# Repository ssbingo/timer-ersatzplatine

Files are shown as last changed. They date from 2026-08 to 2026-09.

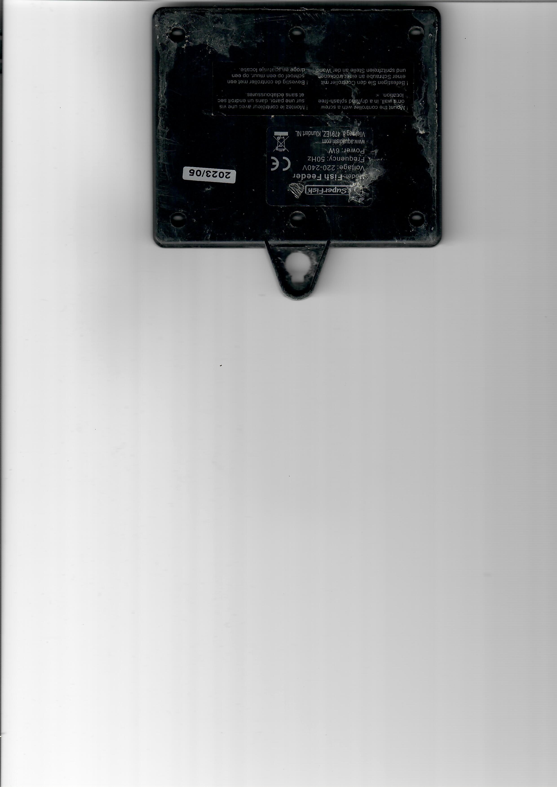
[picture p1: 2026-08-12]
box/aussen.jpg

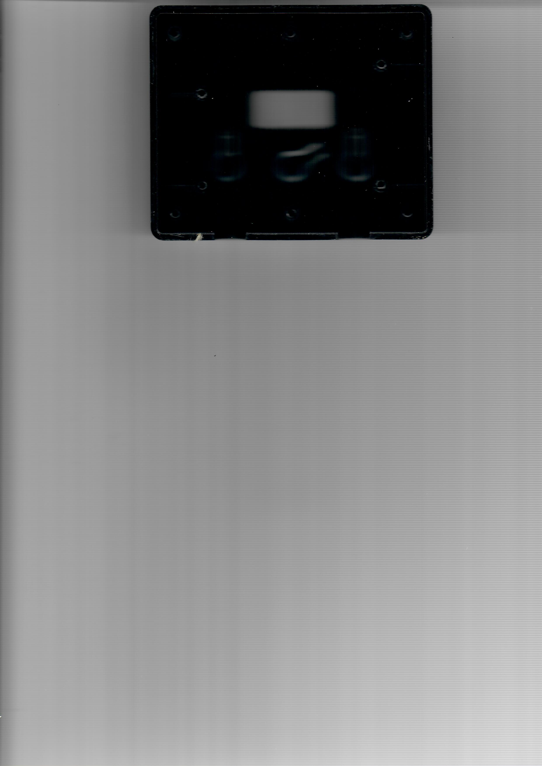
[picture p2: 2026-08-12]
box/Gehauesevorderteil.jpg

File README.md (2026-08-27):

# Feeder-Relais Logo Feeder-Relais

<p align="center">
  <a href="https://www.buymeacoffee.com/ssbingo">Buy me a coffee</a>
</p>

> **Herkunft:** Dieses Projekt ist der Umbau eines **SuperFish / Koi-Pro Fish Feeder** (Futterautomat von Aquadistri — [Produktreihe](https://aquadistri.com/de/brands/koi-pro/einrichtung-zubehoer/zubehoer/) · [Original-Handbuch (PDF)](docs/Koi-Pro-FishFeeder-Original-Manual.pdf)) — die defekte originale Zeitschaltplatine wird ersetzt. **Gehäuse-Rückteil und Platine orientieren sich an den Maßen der Originalsteuerung**, damit beides exakt in das vorhandene Gehäuse passt.

**230-V-Timer-Steuerung zum Selbstbau — ESP32-C3 · OLED · PhotoMOS · externer Shelly 1PM Mini Gen4**

Das Feeder-Relais ist eine selbstgebaute Steuerplatine, die eine 230-Volt-Last
auf Knopfdruck für eine **einstellbare Zeit** einschaltet und danach von allein
wieder abschaltet. Der Name stammt aus dem ursprünglichen Einsatz: Sie ersetzt
die defekte Zeitschaltplatine eines **Futterautomaten** (englisch *feeder*).
Weil sie im Kern nur „einen Schalter für eine gewisse Zeit drückt“, eignet sie
sich für jede Last, die zeitgesteuert geschaltet werden soll — Pumpe,
Futtermotor, Lüfter, Licht.

Drei Taster lösen drei getrennt einstellbare Zeiten aus (Standard 5/10/15 s),
ein OLED zeigt WLAN, Uhrzeit und den Countdown, und eine für Handys optimierte
Weboberfläche erlaubt Bedienung und Konfiguration im Heimnetz — **ohne App und
ohne Cloud**. Das eigentliche Schalten und die Leistungsmessung übernimmt ein
**externer Shelly 1PM Mini Gen4**; die Platine steuert dessen SW-Eingang über ein
**PhotoMOS-Relais galvanisch getrennt** an. Dadurch ist die Kernfunktion
**WLAN-unabhängig**.

> ### ⚠️ 230 Volt — Lebensgefahr
> Netzspannung kann tödlich sein. Aufbau, Prüfung und Inbetriebnahme der
> 230-V-Seite gehören in die Hände einer **Elektrofachkraft** oder unterwiesenen
> Person. Alle Tests, die ohne Fachkraft möglich sind, laufen **ausschließlich
> über USB und ohne jede Netzspannung**. Bitte zuerst Kapitel 2 des Handbuchs
> lesen.

---

## 🌍 Sprachen · Languages

| Sprache | README | Handbuch (PDF) | 🌐 Online |
|---|---|---|---|
| 🇩🇪 **Deutsch** (Original) | [README.md](README.md) | [docs/handbuch/Feeder-Relais-Handbuch.pdf](docs/handbuch/Feeder-Relais-Handbuch.pdf) | [Online](https://ssbingo.github.io/timer-ersatzplatine/) |
| 🇬🇧 English | [docs/en/README.md](docs/en/README.md) | [docs/en/Feeder-Relais-Manual.pdf](docs/en/Feeder-Relais-Manual.pdf) | [Online](https://ssbingo.github.io/timer-ersatzplatine/en.html) |
| 🇫🇷 Français | [docs/fr/README.md](docs/fr/README.md) | [docs/fr/Feeder-Relais-Manuel.pdf](docs/fr/Feeder-Relais-Manuel.pdf) | [Online](https://ssbingo.github.io/timer-ersatzplatine/fr.html) |
| 🇳🇱 Nederlands | [docs/nl/README.md](docs/nl/README.md) | [docs/nl/Feeder-Relais-Handleiding.pdf](docs/nl/Feeder-Relais-Handleiding.pdf) | [Online](https://ssbingo.github.io/timer-ersatzplatine/nl.html) |
| 🇪🇸 Español | [docs/es/README.md](docs/es/README.md) | [docs/es/Feeder-Relais-Manual.pdf](docs/es/Feeder-Relais-Manual.pdf) | [Online](https://ssbingo.github.io/timer-ersatzplatine/es.html) |
| 🇮🇹 Italiano | [docs/it/README.md](docs/it/README.md) | [docs/it/Feeder-Relais-Manuale.pdf](docs/it/Feeder-Relais-Manuale.pdf) | [Online](https://ssbingo.github.io/timer-ersatzplatine/it.html) |

---

## Inhalt

1. [Überblick](#überblick)
2. [Die Signalkette](#die-signalkette)
3. [Die Platine (Hardware v3)](#die-platine-hardware-v3)
4. [Die Firmware](#die-firmware)
5. [Bedienung](#bedienung)
6. [Das Gehäuse (3D-Druck)](#das-gehäuse-3d-druck)
7. [Anbindung an ioBroker](#anbindung-an-iobroker)
8. [Nachbau & Handbuch](#nachbau--handbuch)
9. [Projektstruktur](#projektstruktur)
10. [Status](#status)
11. [Lizenz](#lizenz)

---

## Überblick

Das Gerät ersetzt eine originale Timer-Platine hinter einer vorhandenen
Frontplatte. Es besteht aus vier gut trennbaren Bausteinen:

- **Platine** (`kicad-v3/`) — ESP32-C3, Netzteil, PhotoMOS und die 230-V-Klemmen,
  vierlagig, gesamte Elektronik auf der Rückseite.
- **Firmware** (`firmware/`) — ESPHome-Projekt mit eigener Mobil-Web-App,
  JSON-Schnittstelle, NTP-Uhr, OLED-Anzeige, Status-LED und mehrsprachiger
  Bedienung.
- **Gehäuse** (`box/`) — 3D-gedrucktes Rückteil (35 mm tief), das Platine *und*
  den externen Shelly aufnimmt; das Vorderteil ist die vorhandene Frontplatte.
- **Externer Shelly 1PM Mini Gen4** — das zertifizierte Schaltrelais mit
  Leistungsmessung, außerhalb der Platine verdrahtet.

Die **Aufgabenteilung** ist der Kern des Konzepts: Der ESP misst die Zeit und
gibt ein galvanisch getrenntes Hardware-Signal an den Shelly; der Shelly schaltet
die Last und misst die Leistung. Fällt das WLAN aus, laufen Tasten, Timer und
Schalten trotzdem weiter — nur die Fernbedienung ruht.

## Die Signalkette

Vom Tastendruck bis zur geschalteten Last durchläuft das Signal fünf Stationen,
jede mit genau einer Aufgabe:

```
Taste  ─►  ESP32-C3  ─►  330 Ω  ─►  PhotoMOS  ─►  Shelly 1PM  ─►  Last
S1–S3      zählt die     begrenzt    schaltet      schaltet und     (Pumpe,
           Zeit, malt    den LED-    galvanisch     misst die        Futter-
           das OLED      Strom       getrennt       230-V-Last       motor …)
```

Der ESP arbeitet mit ungefährlichen 3,3 V und darf 230 V niemals direkt berühren.
Der **PhotoMOS** ist die Brücke: Er trennt Klein- und Netzspannung vollständig
durch *Licht*. Der Shelly wird auf **Switch/Follow** gestellt — sein Relais ist
genau so lange an, wie unser Signal anliegt; das gesamte Timing bleibt beim ESP.

## Die Platine (Hardware v3)

Die aktuelle Version 3 liegt fertig als KiCad-Projekt unter `kicad-v3/`.

- **Außenmaß** 101,6 × 77,5 mm, **vierlagig** (1,6 mm).
- **Gesamte Elektronik auf der Rückseite** — vorne bleiben nur die drei Taster
  und die OLED-Buchse (alles, was bedient oder gesehen wird).
- Die beiden **Innenlagen sind durchgehende Masseflächen** im
  Kleinspannungsbereich → störungsarm, stabiles WLAN.
- **Netzspannung nur außen:** Die fünf 230-V-Netze liegen ausschließlich auf den
  Außenlagen, unten links, in einer eigenen Netzklasse mit breiteren Bahnen.
- **6-mm-Kriechstrecke** zwischen jedem 230-V-Netz und jeder Kleinspannung — als
  feste KiCad-Prüfregel (`.kicad_dru`) hinterlegt. Einzige Ausnahme ist das
  PhotoMOS K1: Sein Gehäuse *ist* die zertifizierte Trennstelle.

### GPIO-Belegung — verbindlicher Abgleich Platine ↔ Firmware

Diese Zuordnung muss auf beiden Seiten exakt übereinstimmen, sonst funktioniert
das Gerät nicht:

| ESP-Pin | Firmware | Platine / Netz | Funktion |
|---|---|---|---|
| **GPIO3** | `btn_s1` (Eingang, Pull-up, invertiert) | Pad 3 → `/BTN1` | Taster **S1 Down/Manual** (T1) → Timer 1 |
| **GPIO4** | `btn_s2` | Pad 4 → `/BTN2` | Taster **S2 SET** (T2) → Timer 2 / lang: Menü |
| **GPIO5** | `btn_s3` | Pad 5 → `/BTN3` | Taster **S3 UP** (T3) → Timer 3 / lang: Stop |
| **GPIO6** | `shelly_trigger` (Ausgang) | Pad 6 → `/PMOS_DRV` → R1 330 Ω → K1-LED | PhotoMOS-Treiber: HIGH = Last ein |
| **GPIO7** | `i2c: sda` (400 kHz) | Pad 7 → `/SDA` → OLED J2.4 | I²C-Datenleitung zum OLED |
| **GPIO8** | `status_led` (WS2812, GRB) | modulintern (Pad 8 frei) | Onboard-RGB-Status-LED (Ampel) |
| **GPIO9** | `i2c: scl` (400 kHz) | Pad 9 → `/SCL` → OLED J2.3 | I²C-Taktleitung zum OLED (Adresse 0x3C) |
| **5V / GND** | Modulversorgung | `/+5V` / `GND` vom Netzteil | Versorgung + gemeinsame Masse |
| **3V3** | Onboard-Regler | `/+3V3` → OLED-VCC | 3,3 V für das OLED |

> **Wichtig:** SDA liegt bewusst auf **GPIO7**, nicht GPIO8 — auf GPIO8 sitzt die
> Onboard-WS2812. Läge dort I²C, bliebe das OLED schwarz und der Datenverkehr
> würde die LED stören.

### Anschlussklemmen und Netze

| Klemme | Anschluss | Belegung |
|---|---|---|
| **X1** | Netzeingang | 1 = N, 2 = L_IN (230 V herein) |
| **X2** | Lastabgang | 1 = O (geschaltet), 2 = N |
| **X3** | Snubber | 1 = O, 2 = N — optionales RC-Glied für induktive Lasten |
| **J1** | Shelly (extern) | 1 = SW, 2 = O, 3 = L, 4 = N |
| **J2** | OLED | GND / VCC / SCL / SDA (aufgesteckt) |

Die fünf 230-V-Netze der Netzklasse „230V“: `L_IN` (ungesichert, X1→F1),
`L_F` (abgesichert, F1→RV1/PS1/K1.3/Shelly-L), `N` (Neutral), `SW_SHELLY`
(geschaltet, K1.4→Shelly-SW) und `O_LAST` (geschaltet, Shelly-O→X2/X3).

### Wichtige Bauteile

| Kennung | Bauteil | Funktion |
|---|---|---|
| **U1** | ESP32-C3 Super Mini | Mikrocontroller mit WLAN, 5 V→3,3 V; trägt die WS2812 auf GPIO8 |
| **K1** | PhotoMOS G3VM-601AY2 (o. -601BY / AQY216) | Galvanische Trennung 3,3 V ↔ 230 V, **≥ 400 V** |
| **PS1** | AC/DC-Modul TSP-05 (5 V / 3 W) | Netzteil aus L_F + N |
| **R1** | 330 Ω | Vorwiderstand der K1-LED (~6 mA) |
| **C1 / C2** | 220 µF / 100 nF | 5-V-Puffer (WLAN-Spitzen) + Abblockung |
| **F1** | 1 A träge, 5×20 mm | primärseitige Feinsicherung (X1→F1→L_F) |
| **RV1** | Varistor S14K275 | Überspannungsschutz zwischen L_F und N |
| **SW1–3** | Taster 6×6 mm | die drei Kurzhubtaster (Position fix, Frontplatte) |

## Die Firmware

Die Firmware ist ein **ESPHome**-Projekt (`firmware/timer-relais-c3.yaml`) mit
eigenen C++-Erweiterungen. Gerätename/Hostname: **`feeder-relais`**
(→ `http://feeder-relais.local`).

- **Timer-Logik:** drei unabhängige Zeiten (1–600 s), im laufenden Betrieb per
  Web änderbar; kurzer Tastendruck startet, langer Druck auf UP stoppt alles.
- **Eigene Mobil-Web-App + JSON-API** (`firmware/timer_web.h`) auf Port 80 —
  kein Cloud-Dienst. Endpunkte: `/api/status`, `/api/trigger`, `/api/stop`,
  `/api/config`, `/api/net`, `/api/wifi`, `/api/reboot`.
- **OLED-Anzeige** (SSD1306 128×32): WLAN-Empfang, große NTP-Uhr, Datum, freier
  Speicher; im Timerlauf der Sekunden-Countdown. Anzeige um 180° gedreht (an die
  Einbaulage angepasst).
- **Status-Ampel** über die Onboard-WS2812 (GPIO8): **grün** = bereit,
  **gelb** = Timer läuft, **rot** = Störung.
- **Netzwerk-Konfiguration zur Laufzeit** (`firmware/net_config.h`): IP-Modus
  DHCP/statisch, NTP-Server, Hostname, 802.11k/v-Roaming.
- **Mehrsprachig** (Web + OLED): Deutsch / Englisch / Französisch, geräteweit
  umschaltbar.
- **Provisioning per Captive-Portal** — kein WLAN-Passwort einkompiliert; die
  Zugangsdaten überstehen ein Update.
- **Drahtlose Updates (OTA)** über `web_server`-Plattform (`POST /update`) sowie
  ein Log-/Debug-Ringpuffer (`/api/log`).

Fertige Flash-Images (factory + OTA) liegen unter `firmware/build/`.

## Bedienung

**Am Gerät** — drei Taster:

| Taste | kurz | lang |
|---|---|---|
| **S1** Down/Manual | Timer 1 auslösen | — |
| **S2** SET | Timer 2 auslösen | ≥ 3 s: Info-Menü (mit S1/S3 blättern) |
| **S3** UP | Timer 3 auslösen | ≥ 1,2 s: alle Timer stoppen |

**Mobil** — im Browser `http://feeder-relais.local`: Timer auslösen, die drei
Zeiten einstellen, Netzwerk- und Statuswerte einsehen, Sprache wählen.

## Das Gehäuse (3D-Druck)

Das Gehäuse besteht aus dem vorhandenen **Vorderteil** (Originalfrontplatte mit
Sichtfenster und Tast-Stößeln) und einem selbst gedruckten **Rückteil**:

- **Produktionsgehäuse:** `box/feeder_back_Shelly_35mm.stl` — das zu druckende
  Rückteil **mit integrierten Halterungen für den Shelly und den Snubber**.
- Basis-/Parametervariante: `box/feeder_back.scad` (OpenSCAD) → `box/feeder_back_35mm.stl`
  (ohne Shelly-/Snubber-Halter), zum Anpassen der Maße.
- **35 mm tief** (statt originaler 5,7 mm), damit Platine *und* Shelly hineinpassen;
  Außenmaß 109,8 × 90,8 mm.
- Wandaufbau: Dichtkante oben **1,3 mm**, verstärkte Außenwand darunter **2,5 mm**,
  Boden **2,5 mm**. Sechs Schraubdome (Raster 45 × 70 mm) mit tiefem Senkkanal für
  die kurzen Originalschrauben; Aufhängelasche mit Schlüsselloch.
- `box/Timer-Ersatzplatine-v3-BOARD.stl` ist eine **1:1-Attrappe** der Platine —
  flach drucken und einlegen, um die Passung zu prüfen, **bevor** die echte
  Platine bestellt wird.

## Anbindung an ioBroker

Das Feeder-Relais ist die **Hardware-Seite** eines Futterautomaten und lässt sich
gut in eine Hausautomatisierung einbinden:

- Der **externe Shelly 1PM Mini Gen4** wird in ioBroker über den
  **Shelly-Adapter** nativ eingebunden — Schaltzustand und Leistungsmessung sind
  dort direkt sichtbar und steuerbar.
- Die **eigene JSON-API** des Geräts (`/api/status | trigger | stop | config`)
  lässt sich per REST/Skript (z. B. `simple-api`, JavaScript-Adapter) auslesen
  und bedienen — für Timer-Auslösung und Statusabfrage. Ein Timer-Start lässt sich
  mit `&src=adapter` kennzeichnen; die Quelle des letzten Starts steht dann im
  Status-Feld `trg` (`button`/`api`/`adapter`) und in einer Log-Zeile der Platine.

Im selben „Smart-Pond/Feeder“-Umfeld gibt es zwei passende Adapter desselben
Autors, die die **Software-Seite** bilden:

- **[ioBroker.automatic-feeder](https://github.com/ssbingo/ioBroker.automatic-feeder)**
  — Zeitplanung, Temperaturmodell, Sonnenauf-/-untergang, Pausen und
  Benachrichtigungen für einen Fisch-/Koi-/Teichfutterautomaten.
- **[ioBroker.vis-2-widgets-automatic-feeder](https://github.com/ssbingo/ioBroker.vis-2-widgets-automatic-feeder)**
  — fertige vis-2-Dashboard-Widgets (Live-Ansicht und Fernbedienung) für den
  Adapter oben.

So bildet die Hardware (dieses Gerät + Shelly) zusammen mit den beiden Adaptern
eine durchgängige Kette von der Taste bis zum Dashboard.

## Nachbau & Handbuch

Ein **vollständiges, anfängertaugliches Handbuch** führt Schritt für Schritt vom
leeren Board bis zum fertigen Gerät — mit Sicherheit, Einkaufsliste,
Platinenfertigung, Bestückung, Firmware-Flashen und Inbetriebnahme, inklusive
klickbarem Inhaltsverzeichnis:

**➡️ [docs/handbuch/Feeder-Relais-Handbuch.pdf](docs/handbuch/Feeder-Relais-Handbuch.pdf)**
(Übersetzungen siehe [Sprachen-Tabelle](#-sprachen--languages) oben.)

Firmware flashen (ESP per USB-C):

```bash
esphome run firmware/timer-relais-c3.yaml
```

## Projektstruktur

```
kicad-v3/     Platine v3 (KiCad: Schaltplan, Layout, 6-mm-Regel, Footprints, 3D-Modelle)
box/          Gehäuse-Rückteil (OpenSCAD-Quelle + STL) und Platinen-Attrappe
firmware/     ESPHome-Firmware (.yaml + .h), fertige Flash-Images in build/
docs/         Handbuch-PDF (deutsch) und Übersetzungen unter docs/<sprache>/
README.md     dieses Dokument (deutsch; Übersetzungen unter docs/<sprache>/)
```

## Status

**Version 3 fertig entwickelt — vor der Fertigung.** Platine 4-lagig geroutet
(DRC ohne echte Fehler), Board ↔ Firmware abgeglichen (OLED-SDA auf GPIO7),
Gehäuse und Dokumentation fertig. Offen: Gerber frisch erzeugen, Passprobe der
Attrappe, 4-Lagen-Bestellung, Aufbau und Funktionstest.

## Lizenz

Dieses Projekt (Hardware, Firmware, Gehäuse und Dokumentation) steht unter der
Lizenz **Creative Commons Namensnennung – Nicht kommerziell – Weitergabe unter
gleichen Bedingungen 4.0 International (CC BY-NC-SA 4.0)**.

© 2026 Silvio Sternitzke

Es steht dir frei:

- **Teilen** — das Material vervielfältigen und weiterverbreiten,
- **Bearbeiten** — es umgestalten und darauf aufbauen,

unter den folgenden Bedingungen:

- **Namensnennung (BY)** — nenne den Urheber, verlinke die Lizenz und gib an, ob
  Änderungen vorgenommen wurden.
- **Nicht kommerziell (NC)** — nicht für kommerzielle Zwecke.
- **Weitergabe unter gleichen Bedingungen (SA)** — Bearbeitungen müssen unter
  derselben Lizenz weitergegeben werden.
- **Keine weiteren Einschränkungen** — keine zusätzlichen Klauseln oder
  technischen Maßnahmen, die anderen etwas rechtlich Erlaubtes verwehren.

Lizenztext: <https://creativecommons.org/licenses/by-nc-sa/4.0/deed.de> ·
vollständiger Rechtstext siehe [LICENSE](LICENSE).

> **Haftungsausschluss:** Der Nachbau erfolgt auf eigene Verantwortung.
> 230 Volt sind lebensgefährlich. Das Material wird ohne Gewähr bereitgestellt;
> jede Haftung für Schäden ist ausgeschlossen. Im Zweifel eine Elektrofachkraft
> hinzuziehen.

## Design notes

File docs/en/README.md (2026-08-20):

# Feeder-Relais Logo Feeder-Relais

<p align="center">
  <a href="https://www.buymeacoffee.com/ssbingo">Buy me a coffee</a>
</p>

> **Origin:** This project is a conversion of a **SuperFish / Koi-Pro Fish Feeder** (an automatic feeder by Aquadistri — [product range](https://aquadistri.com/de/brands/koi-pro/einrichtung-zubehoer/zubehoer/) · [original manual (PDF)](../Koi-Pro-FishFeeder-Original-Manual.pdf)) — it replaces the defective original timer board. **The case back and the PCB follow the dimensions of the original controller**, so both fit exactly into the existing housing.

**A DIY 230 V timer controller — ESP32-C3 · OLED · PhotoMOS · external Shelly 1PM Mini Gen4**

The Feeder-Relais is a DIY control board that switches on a 230 V load at
the press of a button for an **adjustable time** and then switches itself
off again automatically. The name comes from its original use case: it
replaces the defective timer board of an automatic **feeder** — hence the
product name. Because at its core it just "presses a switch for a certain
time," it is suitable for any load that needs to be switched on a timer —
pump, feed motor, fan, light.

Three buttons trigger three independently adjustable times (default
5/10/15 s), an OLED shows the Wi-Fi status, the time, and the countdown, and
a mobile-optimized web interface allows operation and configuration on the
home network — **without an app and without the cloud**. The actual
switching and power measurement are handled by an **external Shelly 1PM Mini
Gen4**; the board drives its SW input via a **galvanically isolated PhotoMOS
relay**. This makes the core function **independent of Wi-Fi**.

> ### ⚠️ 230 Volts — Danger to Life
> Mains voltage can be fatal. Building, testing, and commissioning the 230 V
> side must be done by a **qualified electrician** or a person trained and
> instructed in electrical safety. All tests that are possible without a
> qualified electrician are carried out in this project **exclusively via
> USB and without any mains voltage**. Please read Chapter 2 of the manual
> first.

---

## 🌍 Sprachen · Languages

| Sprache | README | Handbuch (PDF) | 🌐 Online |
|---|---|---|---|
| 🇩🇪 **Deutsch** (Original) | [README.md](README.md) | [docs/handbuch/Feeder-Relais-Handbuch.pdf](docs/handbuch/Feeder-Relais-Handbuch.pdf) | [Online](https://ssbingo.github.io/timer-ersatzplatine/) |
| 🇬🇧 English | [docs/en/README.md](docs/en/README.md) | [docs/en/Feeder-Relais-Manual.pdf](docs/en/Feeder-Relais-Manual.pdf) | [Online](https://ssbingo.github.io/timer-ersatzplatine/en.html) |
| 🇫🇷 Français | [docs/fr/README.md](docs/fr/README.md) | [docs/fr/Feeder-Relais-Manuel.pdf](docs/fr/Feeder-Relais-Manuel.pdf) | [Online](https://ssbingo.github.io/timer-ersatzplatine/fr.html) |
| 🇳🇱 Nederlands | [docs/nl/README.md](docs/nl/README.md) | [docs/nl/Feeder-Relais-Handleiding.pdf](docs/nl/Feeder-Relais-Handleiding.pdf) | [Online](https://ssbingo.github.io/timer-ersatzplatine/nl.html) |
| 🇪🇸 Español | [docs/es/README.md](docs/es/README.md) | [docs/es/Feeder-Relais-Manual.pdf](docs/es/Feeder-Relais-Manual.pdf) | [Online](https://ssbingo.github.io/timer-ersatzplatine/es.html) |
| 🇮🇹 Italiano | [docs/it/README.md](docs/it/README.md) | [docs/it/Feeder-Relais-Manuale.pdf](docs/it/Feeder-Relais-Manuale.pdf) | [Online](https://ssbingo.github.io/timer-ersatzplatine/it.html) |

---

## Contents

1. [Overview](#overview)
2. [The Signal Chain](#the-signal-chain)
3. [The PCB (Hardware v3)](#the-pcb-hardware-v3)
4. [The Firmware](#the-firmware)
5. [Operation](#operation)
6. [The Enclosure (3D Printing)](#the-enclosure-3d-printing)
7. [Integration with ioBroker](#integration-with-iobroker)
8. [Building Your Own & Manual](#building-your-own--manual)
9. [Project Structure](#project-structure)
10. [Status](#status)
11. [License](#license)

---

## Overview

The device replaces an original timer board behind an existing front panel.
It consists of four cleanly separable building blocks:

- **PCB** (`kicad-v3/`) — ESP32-C3, power supply, PhotoMOS, and the 230 V
  terminal blocks; four layers, all electronics on the back.
- **Firmware** (`firmware/`) — an ESPHome project with its own mobile web
  app, JSON interface, NTP clock, OLED display, status LED, and
  multilingual operation.
- **Enclosure** (`box/`) — a 3D-printed back piece (35 mm deep) that houses
  the board *and* the external Shelly; the front piece is the existing
  front panel.
- **External Shelly 1PM Mini Gen4** — the certified switching relay with
  power measurement, wired outside the board.

This **division of labor** is at the core of the concept: the ESP measures
the time and sends a galvanically isolated hardware signal to the Shelly;
the Shelly switches the load and measures the power. If Wi-Fi goes down,
the buttons, timer, and switching keep working regardless — only remote
control is paused.

## The Signal Chain

From the button press to the switched load, the signal passes through five
stages, each with exactly one job:

```
Button ─►  ESP32-C3  ─►  330 Ω  ─►  PhotoMOS  ─►  Shelly 1PM  ─►  Load
S1–S3      counts the    limits      switches       switches and     (pump,
           time, draws   the LED     galvanically   measures the      feed
           the OLED      current     isolated       230 V load        motor …)
```

The ESP operates at a safe 3,3 V and must never touch 230 V directly. The
**PhotoMOS** is the bridge: it completely isolates low voltage from mains
voltage using *light*. The Shelly is set to **Switch/Follow** — its relay is
on for exactly as long as our signal is present; all the timing stays with
the ESP.

## The PCB (Hardware v3)

The current version 2 is complete as a KiCad project under `kicad-v3/`.

- **Outer dimensions** 101,6 × 77,5 mm, **four layers** (1,6 mm).
- **All electronics on the back** — only the three buttons and the OLED
  socket remain on the front (everything that is operated or seen).
- Both **inner layers are continuous ground planes** in the low-voltage
  area → low interference, stable Wi-Fi.
- **Mains voltage only on the outer layers:** the five 230 V nets are
  located exclusively on the outer layers, in the bottom left, in their own
  net class with wider traces.
- **6 mm creepage distance** between every 230 V net and every low-voltage
  net — enforced as a fixed KiCad design rule (`.kicad_dru`). The only
  exception is the PhotoMOS K1: its package *is* the certified isolation
  barrier.

### GPIO Assignment — Mandatory PCB ↔ Firmware Alignment

This mapping must match exactly on both sides, or the device will not work:

| ESP Pin | Firmware | Board / Net | Function |
|---|---|---|---|
| **GPIO3** | `btn_s1` (input, pull-up, inverted) | Pad 3 → `/BTN1` | Button **S1 Down/Manual** (T1) → Timer 1 |
| **GPIO4** | `btn_s2` | Pad 4 → `/BTN2` | Button **S2 SET** (T2) → Timer 2 / long press: menu |
| **GPIO5** | `btn_s3` | Pad 5 → `/BTN3` | Button **S3 UP** (T3) → Timer 3 / long press: stop |
| **GPIO6** | `shelly_trigger` (output) | Pad 6 → `/PMOS_DRV` → R1 330 Ω → K1-LED | PhotoMOS driver: HIGH = load on |
| **GPIO7** | `i2c: sda` (400 kHz) | Pad 7 → `/SDA` → OLED J2.4 | I²C data line to the OLED |
| **GPIO8** | `status_led` (WS2812, GRB) | on-module (Pad 8 unused) | Onboard RGB status LED (traffic light) |
| **GPIO9** | `i2c: scl` (400 kHz) | Pad 9 → `/SCL` → OLED J2.3 | I²C clock line to the OLED (address 0x3C) |
| **5V / GND** | Module supply | `/+5V` / `GND` from the power supply | Supply + common ground |
| **3V3** | Onboard regulator | `/+3V3` → OLED-VCC | 3,3 V for the OLED |

> **Important:** SDA is deliberately on **GPIO7**, not GPIO8 — the onboard
> WS2812 sits on GPIO8. If I²C were there instead, the OLED would stay black
> and the data traffic would interfere with the LED.

### Terminal Blocks and Nets

| Terminal | Connection | Pinout |
|---|---|---|
| **X1** | Mains input | 1 = N, 2 = L_IN (230 V in) |
| **X2** | Load output | 1 = O (switched), 2 = N |
| **X3** | Snubber | 1 = O, 2 = N — optional RC network for inductive loads |
| **J1** | Shelly (external) | 1 = SW, 2 = O, 3 = L, 4 = N |
| **J2** | OLED | GND / VCC / SCL / SDA (plugged on) |

The five 230 V nets in the "230V" net class: `L_IN` (unfused, X1→F1), `L_F`
(fused, F1→RV1/PS1/K1.3/Shelly-L), `N` (neutral), `SW_SHELLY` (switched,
K1.4→Shelly-SW), and `O_LAST` (switched, Shelly-O→X2/X3).

### Key Components

| Reference | Component | Function |
|---|---|---|
| **U1** | ESP32-C3 Super Mini | Microcontroller with Wi-Fi, 5 V→3,3 V; carries the WS2812 on GPIO8 |
| **K1** | PhotoMOS G3VM-601AY2 (or -601BY / AQY216) | Galvanic isolation 3,3 V ↔ 230 V, **≥ 400 V** |
| **PS1** | AC/DC module TSP-05 (5 V / 3 W) | Power supply from L_F + N |
| **R1** | 330 Ω | Series resistor for the K1 LED (~6 mA) |
| **C1 / C2** | 220 µF / 100 nF | 5 V buffer (Wi-Fi peaks) + decoupling |
| **F1** | 1 A slow-blow, 5×20 mm | Primary-side fine fuse (X1→F1→L_F) |
| **RV1** | Varistor S14K275 | Overvoltage protection between L_F and N |
| **SW1–3** | Push button 6×6 mm | the three tactile switches (fixed position, front panel) |

## The Firmware

The firmware is an **ESPHome** project (`firmware/timer-relais-c3.yaml`)
with custom C++ extensions. Device name/hostname: **`feeder-relais`**
(→ `http://feeder-relais.local`).

- **Timer logic:** three independent times (1–600 s), changeable via the
  web while running; a short button press starts, a long press on UP stops
  everything.
- **Own mobile web app + JSON API** (`firmware/timer_web.h`) on port 80 —
  no cloud service. Endpoints: `/api/status`, `/api/trigger`, `/api/stop`,
  `/api/config`, `/api/net`, `/api/wifi`, `/api/reboot`.
- **OLED display** (SSD1306 128×32): Wi-Fi reception, a large NTP clock,
  date, free memory; a seconds countdown while a timer is running. Display
  rotated 180° (adapted to the installed orientation).
- **Status traffic light** via the onboard WS2812 (GPIO8): **green** =
  ready, **yellow** = timer running, **red** = fault.
- **Runtime network configuration** (`firmware/net_config.h`): IP mode
  DHCP/static, NTP server, hostname, 802.11k/v roaming.
- **Multilingual** (web + OLED): German / English / French, switchable
  device-wide.
- **Provisioning via captive portal** — no Wi-Fi password compiled in; the
  credentials survive an update.
- **Wireless updates (OTA)** via the `web_server` platform (`POST
  /update`), plus a log/debug ring buffer (`/api/log`).

Ready-made flash images (factory + OTA) are located under `firmware/build/`.

## Operation

**On the device** — three buttons:

| Button | short press | long press |
|---|---|---|
| **S1** Down/Manual | trigger timer 1 | — |
| **S2** SET | trigger timer 2 | ≥ 3 s: info menu (scroll with S1/S3) |
| **S3** UP | trigger timer 3 | ≥ 1,2 s: stop all timers |

**On mobile** — in the browser at `http://feeder-relais.local`: trigger
timers, set the three times, view network and status values, choose the
language.

## The Enclosure (3D Printing)

The enclosure consists of the existing **front piece** (original front
panel with viewing window and button plungers) and a self-printed **back
piece**:

- Source `box/feeder_back.scad` (OpenSCAD), ready-made
  `box/feeder_back_35mm.stl`.
- **35 mm deep** (instead of the original 5,7 mm), so that the board *and*
  the Shelly fit inside.
- Six screw bosses (45 × 70 mm grid), a mounting tab with a keyhole slot.
- `box/Timer-Ersatzplatine-v3-BOARD.stl` is a **1:1 mock-up** of the board
  — print it flat and insert it to check the fit **before** ordering the
  real board.

## Integration with ioBroker

The Feeder-Relais is the **hardware side** of an automatic feeder and
integrates well into a home automation system:

- The **external Shelly 1PM Mini Gen4** is integrated natively into
  ioBroker via the **Shelly adapter** — switch state and power measurement
  are directly visible and controllable there.
- The device's **own JSON API** (`/api/status | trigger | stop | config`)
  can be read and operated via REST/script (e.g. `simple-api`, JavaScript
  adapter) — for triggering timers and querying status.

In the same "smart pond/feeder" ecosystem there are two matching adapters
by the same author that form the **software side**:

- **[ioBroker.automatic-feeder](https://github.com/ssbingo/ioBroker.automatic-feeder)**
  — scheduling, temperature model, sunrise/sunset, pauses, and
  notifications for a fish/koi/pond feeder.
- **[ioBroker.vis-2-widgets-automatic-feeder](https://github.com/ssbingo/ioBroker.vis-2-widgets-automatic-feeder)**
  — ready-made vis-2 dashboard widgets (live view and remote control) for
  the adapter above.

Together, the hardware (this device + Shelly) and the two adapters form an
unbroken chain from the button to the dashboard.

## Building Your Own & Manual

A **complete, beginner-friendly manual** guides you step by step from a
blank board to a finished device — covering safety, the shopping list, PCB
fabrication, assembly, flashing the firmware, and commissioning, including
a clickable table of contents:

**➡️ [docs/en/Feeder-Relais-Manual.pdf](docs/en/Feeder-Relais-Manual.pdf)**
(For other translations, see the [language table](#-sprachen--languages) above.)

Flashing the firmware (ESP via USB-C):

```bash
esphome run firmware/timer-relais-c3.yaml
```

## Project Structure

```
kicad-v3/     PCB v3 (KiCad: schematic, layout, 6 mm rule, footprints, 3D models)
box/          Enclosure back (OpenSCAD source + STL) and PCB mock-up
firmware/     ESPHome firmware (.yaml + .h), ready-made flash images in build/
docs/         Manual PDF (German) and translations under docs/<language>/
README.md     this document (German; translations under docs/<language>/)
```

## Status

**Version 3 fully developed — ready for production.** Board routed in 4
layers (DRC with no real errors), board ↔ firmware aligned (OLED SDA on
GPIO7), enclosure and documentation complete. Remaining: regenerate the
Gerber files, fit-check the mock-up, order in 4 layers, assembly, and
functional testing.

## License

This project (hardware, firmware, enclosure, and documentation) is
licensed under **Creative Commons Attribution-NonCommercial-ShareAlike 4.0
International (CC BY-NC-SA 4.0)**.

© 2026 Silvio Sternitzke

You are free to:

- **Share** — copy and redistribute the material,
- **Adapt** — remix, transform, and build upon it,

under the following terms:

- **Attribution (BY)** — you must give appropriate credit, provide a link
  to the license, and indicate if changes were made.
- **NonCommercial (NC)** — you may not use the material for commercial
  purposes.
- **ShareAlike (SA)** — if you remix, transform, or build upon the
  material, you must distribute your contributions under the same license.
- **No additional restrictions** — you may not apply legal terms or
  technological measures that legally restrict others from doing anything
  the license permits.

License summary: <https://creativecommons.org/licenses/by-nc-sa/4.0/deed.en> ·
for the full legal text see [LICENSE](LICENSE).

> **Disclaimer:** Building this project is at your own risk. 230 volts can
> be fatal. The material is provided without warranty; any liability for
> damages is excluded. When in doubt, consult a qualified electrician.

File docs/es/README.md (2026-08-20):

# Feeder-Relais Logo Feeder-Relais

<p align="center">
  <a href="https://www.buymeacoffee.com/ssbingo">Buy me a coffee</a>
</p>

> **Origen:** Este proyecto es una conversión de un **SuperFish / Koi-Pro Fish Feeder** (comedero automático de Aquadistri — [gama de productos](https://aquadistri.com/de/brands/koi-pro/einrichtung-zubehoer/zubehoer/) · [manual original (PDF)](../Koi-Pro-FishFeeder-Original-Manual.pdf)) — sustituye la placa de temporizador original defectuosa. **La parte trasera de la carcasa y la placa siguen las dimensiones del controlador original**, de modo que ambas encajan exactamente en la carcasa existente.

**Control de temporizador de 230 V para autoconstrucción — ESP32-C3 · OLED · PhotoMOS · Shelly 1PM Mini Gen4 externo**

El Feeder-Relais es una placa de control autoconstruida que enciende una carga
de 230 voltios pulsando un botón durante un **tiempo ajustable** y luego se
apaga sola. El nombre proviene de su uso original: sustituye la placa
temporizadora defectuosa de un **comedero automático** (en inglés *feeder*).
Como en el fondo solo «pulsa un interruptor durante un tiempo determinado»,
sirve para cualquier carga que deba conmutarse de forma temporizada — bomba,
motor de alimentación, ventilador, luz.

Tres pulsadores activan tres tiempos ajustables por separado (por defecto
5/10/15 s), una pantalla OLED muestra el WiFi, la hora y la cuenta atrás, y
una interfaz web optimizada para móviles permite el manejo y la configuración
en la red doméstica — **sin app y sin nube**. La conmutación propiamente
dicha y la medición de potencia las realiza un **Shelly 1PM Mini Gen4
externo**; la placa controla su entrada SW mediante un **relé PhotoMOS con
aislamiento galvánico**. Gracias a ello, la función principal es
**independiente del WiFi**.

> ### ⚠️ 230 voltios — Peligro de muerte
> La tensión de red puede ser mortal. El montaje, la comprobación y la
> puesta en marcha del lado de 230 V deben quedar en manos de un
> **electricista cualificado** o una persona instruida. Todas las pruebas
> que se pueden realizar sin personal cualificado se llevan a cabo
> **exclusivamente por USB y sin ninguna tensión de red**. Por favor, lee
> primero el capítulo 2 del manual.

---

## 🌍 Sprachen · Languages

| Sprache | README | Handbuch (PDF) | 🌐 Online |
|---|---|---|---|
| 🇩🇪 **Deutsch** (Original) | [README.md](README.md) | [docs/handbuch/Feeder-Relais-Handbuch.pdf](docs/handbuch/Feeder-Relais-Handbuch.pdf) | [Online](https://ssbingo.github.io/timer-ersatzplatine/) |
| 🇬🇧 English | [docs/en/README.md](docs/en/README.md) | [docs/en/Feeder-Relais-Manual.pdf](docs/en/Feeder-Relais-Manual.pdf) | [Online](https://ssbingo.github.io/timer-ersatzplatine/en.html) |
| 🇫🇷 Français | [docs/fr/README.md](docs/fr/README.md) | [docs/fr/Feeder-Relais-Manuel.pdf](docs/fr/Feeder-Relais-Manuel.pdf) | [Online](https://ssbingo.github.io/timer-ersatzplatine/fr.html) |
| 🇳🇱 Nederlands | [docs/nl/README.md](docs/nl/README.md) | [docs/nl/Feeder-Relais-Handleiding.pdf](docs/nl/Feeder-Relais-Handleiding.pdf) | [Online](https://ssbingo.github.io/timer-ersatzplatine/nl.html) |
| 🇪🇸 Español | [docs/es/README.md](docs/es/README.md) | [docs/es/Feeder-Relais-Manual.pdf](docs/es/Feeder-Relais-Manual.pdf) | [Online](https://ssbingo.github.io/timer-ersatzplatine/es.html) |
| 🇮🇹 Italiano | [docs/it/README.md](docs/it/README.md) | [docs/it/Feeder-Relais-Manuale.pdf](docs/it/Feeder-Relais-Manuale.pdf) | [Online](https://ssbingo.github.io/timer-ersatzplatine/it.html) |

---

## Contenido

1. [Descripción general](#descripción-general)
2. [La cadena de señal](#la-cadena-de-señal)
3. [La placa (hardware v3)](#la-placa-hardware-v3)
4. [El firmware](#el-firmware)
5. [Manejo](#manejo)
6. [La carcasa (impresión 3D)](#la-carcasa-impresión-3d)
7. [Conexión con ioBroker](#conexión-con-iobroker)
8. [Réplica y manual](#réplica-y-manual)
9. [Estructura del proyecto](#estructura-del-proyecto)
10. [Estado](#estado)
11. [Licencia](#licencia)

---

## Descripción general

El dispositivo sustituye una placa temporizadora original detrás de un panel
frontal existente. Consta de cuatro módulos claramente separables:

- **Placa** (`kicad-v3/`) — ESP32-C3, fuente de alimentación, PhotoMOS y los
  bornes de 230 V, de cuatro capas, con toda la electrónica en la cara
  posterior.
- **Firmware** (`firmware/`) — proyecto ESPHome con su propia aplicación web
  móvil, interfaz JSON, reloj NTP, pantalla OLED, LED de estado y manejo
  multilingüe.
- **Carcasa** (`box/`) — parte trasera impresa en 3D (35 mm de profundidad)
  que aloja la placa *y* el Shelly externo; la parte delantera es el panel
  frontal existente.
- **Shelly 1PM Mini Gen4 externo** — el relé de conmutación certificado con
  medición de potencia, cableado fuera de la placa.

El núcleo del concepto es la **división de tareas**: el ESP mide el tiempo y
envía una señal de hardware con aislamiento galvánico al Shelly; el Shelly
conmuta la carga y mide la potencia. Si falla el WiFi, los botones, el
temporizador y la conmutación siguen funcionando — solo el control remoto
queda inactivo.

## La cadena de señal

Desde que se pulsa el botón hasta que se conmuta la carga, la señal recorre
cinco etapas, cada una con una única función:

```
Botón  ─►  ESP32-C3  ─►  330 Ω  ─►  PhotoMOS  ─►  Shelly 1PM  ─►  Carga
S1–S3      cuenta el     limita la   conmuta con    conmuta y        (bomba,
           tiempo,       corriente   aislamiento    mide la carga    motor de
           dibuja el     del LED     galvánico      de 230 V         alimentación,
           OLED                                                      ventilador …)
```

El ESP trabaja con unos inofensivos 3,3 V y no debe «tocar» nunca 230 V
directamente. El **PhotoMOS** es el puente: separa por completo la baja
tensión y la tensión de red mediante *luz*. El Shelly se configura en
**Switch/Follow**: su relé permanece encendido exactamente el tiempo que
nuestra señal esté activa; toda la temporización sigue en manos del ESP.

## La placa (hardware v3)

La versión 2 actual está terminada como proyecto KiCad en `kicad-v3/`.

- **Medida exterior** 101,6 × 77,5 mm, **cuatro capas** (1,6 mm).
- **Toda la electrónica en la cara posterior** — en la parte delantera solo
  quedan los tres pulsadores y el conector OLED (todo lo que se maneja o se
  ve).
- Las dos **capas internas son planos de masa continuos** en la zona de baja
  tensión → bajo nivel de interferencias, WiFi estable.
- **Tensión de red solo en el exterior:** las cinco redes de 230 V se
  encuentran exclusivamente en las capas externas, abajo a la izquierda, en
  una clase de red propia con pistas más anchas.
- **Distancia de fuga de 6 mm** entre cada red de 230 V y cada baja tensión —
  establecida como regla de comprobación fija de KiCad (`.kicad_dru`). La
  única excepción es el PhotoMOS K1: su encapsulado *es* el punto de
  aislamiento certificado.

### Asignación de GPIO — correspondencia vinculante placa ↔ firmware

Esta asignación debe coincidir exactamente en ambos lados; de lo contrario,
el dispositivo no funcionará:

| Pin ESP | Firmware | Placa / red | Función |
|---|---|---|---|
| **GPIO3** | `btn_s1` (entrada, pull-up, invertido) | Pad 3 → `/BTN1` | Pulsador **S1 Down/Manual** (T1) → temporizador 1 |
| **GPIO4** | `btn_s2` | Pad 4 → `/BTN2` | Pulsador **S2 SET** (T2) → temporizador 2 / pulsación larga: menú |
| **GPIO5** | `btn_s3` | Pad 5 → `/BTN3` | Pulsador **S3 UP** (T3) → temporizador 3 / pulsación larga: parada |
| **GPIO6** | `shelly_trigger` (salida) | Pad 6 → `/PMOS_DRV` → R1 330 Ω → K1-LED | Excitador del PhotoMOS: HIGH = carga encendida |
| **GPIO7** | `i2c: sda` (400 kHz) | Pad 7 → `/SDA` → OLED J2.4 | Línea de datos I²C hacia el OLED |
| **GPIO8** | `status_led` (WS2812, GRB) | interno al módulo (Pad 8 libre) | LED RGB de estado integrado (semáforo) |
| **GPIO9** | `i2c: scl` (400 kHz) | Pad 9 → `/SCL` → OLED J2.3 | Línea de reloj I²C hacia el OLED (dirección 0x3C) |
| **5V / GND** | Alimentación del módulo | `/+5V` / `GND` de la fuente de alimentación | Alimentación + masa común |
| **3V3** | Regulador integrado | `/+3V3` → OLED-VCC | 3,3 V para el OLED |

> **Importante:** SDA se ha colocado deliberadamente en **GPIO7**, no en
> GPIO8 — en GPIO8 está el WS2812 integrado. Si ahí estuviera el I²C, el
> OLED se quedaría en negro y el tráfico de datos interferiría con el LED.

### Bornes de conexión y redes

| Borne | Conexión | Asignación |
|---|---|---|
| **X1** | Entrada de red | 1 = N, 2 = L_IN (230 V entrante) |
| **X2** | Salida de carga | 1 = O (conmutado), 2 = N |
| **X3** | Snubber | 1 = O, 2 = N — red RC opcional para cargas inductivas |
| **J1** | Shelly (externo) | 1 = SW, 2 = O, 3 = L, 4 = N |
| **J2** | OLED | GND / VCC / SCL / SDA (enchufable) |

Las cinco redes de 230 V de la clase de red «230V»: `L_IN` (sin proteger,
X1→F1), `L_F` (protegida, F1→RV1/PS1/K1.3/Shelly-L), `N` (neutro),
`SW_SHELLY` (conmutado, K1.4→Shelly-SW) y `O_LAST` (conmutado,
Shelly-O→X2/X3).

### Componentes principales

| Referencia | Componente | Función |
|---|---|---|
| **U1** | ESP32-C3 Super Mini | Microcontrolador con WiFi, 5 V→3,3 V; incorpora el WS2812 en GPIO8 |
| **K1** | PhotoMOS G3VM-601AY2 (o -601BY / AQY216) | Aislamiento galvánico 3,3 V ↔ 230 V, **≥ 400 V** |
| **PS1** | Módulo AC/DC TSP-05 (5 V / 3 W) | Fuente de alimentación a partir de L_F + N |
| **R1** | 330 Ω | Resistencia limitadora del LED de K1 (~6 mA) |
| **C1 / C2** | 220 µF / 100 nF | Amortiguación de 5 V (picos de WiFi) + desacoplo |
| **F1** | 1 A lento, 5×20 mm | fusible de precisión del lado primario (X1→F1→L_F) |
| **RV1** | Varistor S14K275 | Protección contra sobretensión entre L_F y N |
| **SW1–3** | Pulsador 6×6 mm | los tres micropulsadores (posición fija, panel frontal) |

## El firmware

El firmware es un proyecto **ESPHome** (`firmware/timer-relais-c3.yaml`) con
extensiones propias en C++. Nombre del dispositivo/hostname:
**`feeder-relais`** (→ `http://feeder-relais.local`).

- **Lógica del temporizador:** tres tiempos independientes (1–600 s),
  modificables por web durante el funcionamiento; una pulsación corta
  inicia, una pulsación larga en UP detiene todo.
- **Aplicación web móvil propia + API JSON** (`firmware/timer_web.h`) en el
  puerto 80 — sin servicio en la nube. Puntos finales: `/api/status`,
  `/api/trigger`, `/api/stop`, `/api/config`, `/api/net`, `/api/wifi`,
  `/api/reboot`.
- **Pantalla OLED** (SSD1306 128×32): recepción WiFi, reloj NTP grande,
  fecha, memoria libre; durante el temporizador, la cuenta atrás en
  segundos. Pantalla girada 180° (adaptada a la posición de montaje).
- **Semáforo de estado** mediante el WS2812 integrado (GPIO8): **verde** =
  listo, **amarillo** = temporizador en marcha, **rojo** = fallo.
- **Configuración de red en tiempo de ejecución** (`firmware/net_config.h`):
  modo IP DHCP/estático, servidor NTP, hostname, roaming 802.11k/v.
- **Multilingüe** (web + OLED): alemán / inglés / francés, conmutable para
  todo el dispositivo.
- **Aprovisionamiento mediante portal cautivo** — ninguna contraseña WiFi
  está precompilada; las credenciales sobreviven a una actualización.
- **Actualizaciones inalámbricas (OTA)** a través de la plataforma
  `web_server` (`POST /update`), además de un búfer circular de
  registro/depuración (`/api/log`).

Las imágenes de flasheo ya preparadas (factory + OTA) se encuentran en
`firmware/build/`.

## Manejo

**En el dispositivo** — tres pulsadores:

| Botón | corta | larga |
|---|---|---|
| **S1** Down/Manual | Activa el temporizador 1 | — |
| **S2** SET | Activa el temporizador 2 | ≥ 3 s: menú de información (navegar con S1/S3) |
| **S3** UP | Activa el temporizador 3 | ≥ 1,2 s: detiene todos los temporizadores |

**Móvil** — en el navegador `http://feeder-relais.local`: activar el
temporizador, ajustar los tres tiempos, consultar los valores de red y
estado, elegir el idioma.

## La carcasa (impresión 3D)

La carcasa consta de la **parte delantera** existente (panel frontal
original con ventana y varillas pulsadoras) y una **parte trasera** impresa
por uno mismo:

- Fuente `box/feeder_back.scad` (OpenSCAD), archivo listo
  `box/feeder_back_35mm.stl`.
- **35 mm de profundidad** (en lugar de los 5,7 mm originales), para que
  quepan la placa *y* el Shelly.
- Seis columnas de tornillo (retícula 45 × 70 mm), lengüeta de suspensión
  con ojo de cerradura.
- `box/Timer-Ersatzplatine-v3-BOARD.stl` es una **maqueta 1:1** de la placa —
  imprímela plana y colócala dentro para comprobar el ajuste **antes** de
  encargar la placa real.

## Conexión con ioBroker

El Feeder-Relais es el **lado del hardware** de un comedero automático y se
integra bien en una domótica:

- El **Shelly 1PM Mini Gen4 externo** se integra de forma nativa en
  ioBroker mediante el **adaptador Shelly** — el estado de conmutación y la
  medición de potencia son directamente visibles y controlables ahí.
- La **API JSON propia** del dispositivo (`/api/status | trigger | stop |
  config`) puede leerse y manejarse mediante REST/script (p. ej.
  `simple-api`, adaptador JavaScript) — para activar el temporizador y
  consultar el estado.

En el mismo entorno «Smart-Pond/Feeder» existen dos adaptadores adecuados
del mismo autor, que constituyen el **lado del software**:

- **[ioBroker.automatic-feeder](https://github.com/ssbingo/ioBroker.automatic-feeder)**
  — planificación horaria, modelo de temperatura, salida/puesta de sol,
  pausas y notificaciones para un comedero automático de peces/koi/estanque.
- **[ioBroker.vis-2-widgets-automatic-feeder](https://github.com/ssbingo/ioBroker.vis-2-widgets-automatic-feeder)**
  — widgets de panel vis-2 ya preparados (vista en vivo y control remoto)
  para el adaptador anterior.

Así, el hardware (este dispositivo + Shelly) forma junto con los dos
adaptadores una cadena continua desde el botón hasta el panel de control.

## Réplica y manual

Un **manual completo apto para principiantes** guía paso a paso desde la
placa vacía hasta el dispositivo terminado — con seguridad, lista de
compras, fabricación de la placa, montaje, flasheo del firmware y puesta en
marcha, incluyendo un índice con enlaces:

**➡️ [docs/es/Feeder-Relais-Manual.pdf](docs/es/Feeder-Relais-Manual.pdf)**
(para otras traducciones, véase la [tabla de idiomas](#-sprachen--languages)
más arriba.)

Flashear el firmware (ESP por USB-C):

```bash
esphome run firmware/timer-relais-c3.yaml
```

## Estructura del proyecto

```
kicad-v3/     Placa v3 (KiCad: esquemático, layout, regla de 6 mm, footprints, modelos 3D)
box/          Parte trasera de la carcasa (fuente OpenSCAD + STL) y maqueta de la placa
firmware/     Firmware ESPHome (.yaml + .h), imágenes de flasheo listas en build/
docs/         PDF del manual (alemán) y traducciones en docs/<idioma>/
README.md     este documento (alemán; traducciones en docs/<idioma>/)
```

## Estado

**Versión 2 desarrollada por completo — antes de la fabricación.** Placa
enrutada en 4 capas (DRC sin errores reales), placa y firmware coordinados
(OLED-SDA en GPIO7), carcasa y documentación terminadas. Pendiente: generar
los Gerber de nuevo, prueba de ajuste de la maqueta, pedido de 4 capas,
montaje y prueba funcional.

## Licencia

Este proyecto (hardware, firmware, carcasa y documentación) está bajo la
licencia **Creative Commons Reconocimiento – NoComercial – CompartirIgual
4.0 Internacional (CC BY-NC-SA 4.0)**.

© 2026 Silvio Sternitzke

Eres libre de:

- **Compartir** — copiar y redistribuir el material,
- **Adaptar** — remezclarlo y construir a partir de él,

bajo las siguientes condiciones:

- **Reconocimiento (BY)** — debes citar al autor, enlazar la licencia e
  indicar si se han realizado cambios.
- **NoComercial (NC)** — no puede utilizarse con fines comerciales.
- **CompartirIgual (SA)** — las obras derivadas deben distribuirse bajo la
  misma licencia.
- **Sin restricciones adicionales** — no se pueden aplicar cláusulas
  adicionales ni medidas tecnológicas que restrinjan legalmente a otros
  hacer lo que la licencia permite.

Texto de la licencia:
<https://creativecommons.org/licenses/by-nc-sa/4.0/deed.es> · el texto
legal completo se encuentra en [LICENSE](LICENSE).

> **Exención de responsabilidad:** la réplica se realiza bajo la
> responsabilidad propia de cada persona. 230 voltios son mortales. El
> material se ofrece sin garantía; se excluye toda responsabilidad por
> daños. En caso de duda, consulta a un electricista cualificado.

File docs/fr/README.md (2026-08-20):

# Feeder-Relais Logo Feeder-Relais

<p align="center">
  <a href="https://www.buymeacoffee.com/ssbingo">Buy me a coffee</a>
</p>

> **Origine :** Ce projet transforme un **SuperFish / Koi-Pro Fish Feeder** (distributeur automatique d’Aquadistri — [gamme de produits](https://aquadistri.com/de/brands/koi-pro/einrichtung-zubehoer/zubehoer/) · [manuel d’origine (PDF)](../Koi-Pro-FishFeeder-Original-Manual.pdf)) — il remplace la carte de minuterie d’origine défectueuse. **Le fond du boîtier et la carte reprennent les dimensions de la commande d’origine**, afin que les deux s’insèrent exactement dans le boîtier existant.

**Commande de minuterie 230 V à construire soi-même — ESP32-C3 · OLED · PhotoMOS · Shelly 1PM Mini Gen4 externe**

Le Feeder-Relais est une carte de commande faite maison qui met sous tension
une charge 230 volts sur simple pression d'un bouton, pour une
**durée réglable**, puis la coupe automatiquement. Son nom vient de son
usage d'origine : elle remplace la carte de programmation horaire
défectueuse d'un **distributeur de nourriture automatique** (*feeder* en
anglais). Comme elle se contente, au fond, d'« actionner un interrupteur
pendant un certain temps », elle convient à toute charge que l'on souhaite
commander de façon temporisée — pompe, moteur de distribution de
nourriture, ventilateur, éclairage.

Trois boutons déclenchent trois durées réglables séparément (par défaut
5/10/15 s), un OLED affiche le Wi-Fi, l'heure et le compte à rebours, et une
interface web optimisée pour mobile permet la commande et la configuration
sur le réseau domestique — **sans application et sans cloud**. La
commutation proprement dite et la mesure de puissance sont assurées par un
**Shelly 1PM Mini Gen4 externe** ; la carte pilote son entrée SW via un
**relais PhotoMOS à isolation galvanique**. La fonction principale est
ainsi **indépendante du Wi-Fi**.

> ### ⚠️ 230 volts — danger de mort
> La tension secteur peut être mortelle. Le montage, le contrôle et la mise
> en service du côté 230 V doivent être confiés à un(e)
> **électricien(ne) qualifié(e)** ou à une personne formée. Tous les tests
> réalisables sans professionnel se déroulent **exclusivement via USB et
> sans aucune tension secteur**. Merci de lire d'abord le chapitre 2 du
> manuel.

---

## 🌍 Sprachen · Languages

| Sprache | README | Handbuch (PDF) | 🌐 Online |
|---|---|---|---|
| 🇩🇪 **Deutsch** (Original) | [README.md](README.md) | [docs/handbuch/Feeder-Relais-Handbuch.pdf](docs/handbuch/Feeder-Relais-Handbuch.pdf) | [Online](https://ssbingo.github.io/timer-ersatzplatine/) |
| 🇬🇧 English | [docs/en/README.md](docs/en/README.md) | [docs/en/Feeder-Relais-Manual.pdf](docs/en/Feeder-Relais-Manual.pdf) | [Online](https://ssbingo.github.io/timer-ersatzplatine/en.html) |
| 🇫🇷 Français | [docs/fr/README.md](docs/fr/README.md) | [docs/fr/Feeder-Relais-Manuel.pdf](docs/fr/Feeder-Relais-Manuel.pdf) | [Online](https://ssbingo.github.io/timer-ersatzplatine/fr.html) |
| 🇳🇱 Nederlands | [docs/nl/README.md](docs/nl/README.md) | [docs/nl/Feeder-Relais-Handleiding.pdf](docs/nl/Feeder-Relais-Handleiding.pdf) | [Online](https://ssbingo.github.io/timer-ersatzplatine/nl.html) |
| 🇪🇸 Español | [docs/es/README.md](docs/es/README.md) | [docs/es/Feeder-Relais-Manual.pdf](docs/es/Feeder-Relais-Manual.pdf) | [Online](https://ssbingo.github.io/timer-ersatzplatine/es.html) |
| 🇮🇹 Italiano | [docs/it/README.md](docs/it/README.md) | [docs/it/Feeder-Relais-Manuale.pdf](docs/it/Feeder-Relais-Manuale.pdf) | [Online](https://ssbingo.github.io/timer-ersatzplatine/it.html) |

---

## Sommaire

1. [Aperçu](#aperçu)
2. [La chaîne de signal](#la-chaîne-de-signal)
3. [La carte (matériel v3)](#la-carte-matériel-v3)
4. [Le firmware](#le-firmware)
5. [Utilisation](#utilisation)
6. [Le boîtier (impression 3D)](#le-boîtier-impression-3d)
7. [Intégration avec ioBroker](#intégration-avec-iobroker)
8. [Reproduction et manuel](#reproduction-et-manuel)
9. [Structure du projet](#structure-du-projet)
10. [Statut](#statut)
11. [Licence](#licence)

---

## Aperçu

L'appareil remplace une carte de minuterie d'origine derrière une façade
existante. Il se compose de quatre blocs bien séparables :

- **Carte** (`kicad-v3/`) — ESP32-C3, alimentation, PhotoMOS et les bornes
  230 V, quatre couches, électronique entièrement au dos.
- **Firmware** (`firmware/`) — projet ESPHome avec sa propre application
  web mobile, interface JSON, horloge NTP, affichage OLED, LED d'état et
  commande multilingue.
- **Boîtier** (`box/`) — partie arrière imprimée en 3D (35 mm de
  profondeur) qui accueille la carte *et* le Shelly externe ; la partie
  avant est la façade existante.
- **Shelly 1PM Mini Gen4 externe** — le relais de commutation certifié avec
  mesure de puissance, câblé à l'extérieur de la carte.

La **répartition des tâches** est au cœur du concept : l'ESP mesure le
temps et envoie un signal matériel isolé galvaniquement au Shelly ; le
Shelly commute la charge et mesure la puissance. Si le Wi-Fi tombe en
panne, les boutons, la minuterie et la commutation continuent malgré tout
de fonctionner — seule la télécommande est alors au repos.

## La chaîne de signal

De la pression du bouton jusqu'à la charge commutée, le signal traverse
cinq étapes, chacune avec exactement une tâche :

```
Bouton ─►  ESP32-C3  ─►  330 Ω  ─►  PhotoMOS  ─►  Shelly 1PM  ─►  Charge
S1–S3      compte le     limite      commute       commute et       (pompe,
           temps, dessine le courant   isolation    mesure la        moteur
           l'OLED         de la LED   galvanique     charge 230 V     d'aliment. …)
```

L'ESP fonctionne avec des 3,3 V sans danger et ne doit jamais toucher
directement 230 V. Le **PhotoMOS** est le pont entre les deux mondes : il
isole complètement basse tension et tension secteur par la *lumière*. Le
Shelly est réglé sur **Switch/Follow** — son relais reste activé exactement
aussi longtemps que notre signal est présent ; tout le minutage reste du
côté de l'ESP.

## La carte (matériel v3)

La version 2 actuelle est disponible, terminée, sous forme de projet KiCad
dans `kicad-v3/`.

- **Dimensions extérieures** 101,6 × 77,5 mm, **quatre couches** (1,6 mm).
- **Électronique entièrement au dos** — à l'avant ne restent que les trois
  boutons et le connecteur OLED (tout ce qui est actionné ou visible).
- Les deux **couches internes sont des plans de masse continus** dans la
  zone basse tension → peu de perturbations, Wi-Fi stable.
- **Tension secteur uniquement à l'extérieur :** les cinq nets 230 V se
  trouvent exclusivement sur les couches externes, en bas à gauche, dans
  une classe de réseau dédiée avec des pistes plus larges.
- **Ligne de fuite de 6 mm** entre chaque net 230 V et chaque basse
  tension — inscrite comme règle de contrôle KiCad fixe (`.kicad_dru`). La
  seule exception est le PhotoMOS K1 : son boîtier *est* le point de
  séparation certifié.

### Brochage GPIO — correspondance obligatoire carte ↔ firmware

Cette correspondance doit être exactement identique des deux côtés, sinon
l'appareil ne fonctionne pas :

| Broche ESP | Firmware | Carte / net | Fonction |
|---|---|---|---|
| **GPIO3** | `btn_s1` (entrée, pull-up, inversé) | Pad 3 → `/BTN1` | Bouton **S1 Down/Manual** (T1) → minuterie 1 |
| **GPIO4** | `btn_s2` | Pad 4 → `/BTN2` | Bouton **S2 SET** (T2) → minuterie 2 / long : menu |
| **GPIO5** | `btn_s3` | Pad 5 → `/BTN3` | Bouton **S3 UP** (T3) → minuterie 3 / long : arrêt |
| **GPIO6** | `shelly_trigger` (sortie) | Pad 6 → `/PMOS_DRV` → R1 330 Ω → LED K1 | Pilote du PhotoMOS : HIGH = charge activée |
| **GPIO7** | `i2c: sda` (400 kHz) | Pad 7 → `/SDA` → OLED J2.4 | Ligne de données I²C vers l'OLED |
| **GPIO8** | `status_led` (WS2812, GRB) | interne au module (pad 8 libre) | LED RVB d'état embarquée (voyant) |
| **GPIO9** | `i2c: scl` (400 kHz) | Pad 9 → `/SCL` → OLED J2.3 | Ligne d'horloge I²C vers l'OLED (adresse 0x3C) |
| **5V / GND** | alimentation du module | `/+5V` / `GND` depuis l'alimentation | Alimentation + masse commune |
| **3V3** | régulateur embarqué | `/+3V3` → OLED-VCC | 3,3 V pour l'OLED |

> **Important :** SDA se trouve délibérément sur **GPIO7**, pas GPIO8 — sur
> GPIO8 se trouve la WS2812 embarquée. Si l'I²C s'y trouvait, l'OLED
> resterait noir et le trafic de données perturberait la LED.

### Bornes de raccordement et nets

| Borne | Raccordement | Brochage |
|---|---|---|
| **X1** | Entrée secteur | 1 = N, 2 = L_IN (230 V entrant) |
| **X2** | Sortie de charge | 1 = O (commuté), 2 = N |
| **X3** | Snubber | 1 = O, 2 = N — circuit RC optionnel pour charges inductives |
| **J1** | Shelly (externe) | 1 = SW, 2 = O, 3 = L, 4 = N |
| **J2** | OLED | GND / VCC / SCL / SDA (enfiché) |

Les cinq nets 230 V de la classe de réseau « 230V » : `L_IN` (non protégé,
X1→F1), `L_F` (protégé, F1→RV1/PS1/K1.3/Shelly-L), `N` (neutre),
`SW_SHELLY` (commuté, K1.4→Shelly-SW) et `O_LAST` (commuté,
Shelly-O→X2/X3).

### Composants importants

| Repère | Composant | Fonction |
|---|---|---|
| **U1** | ESP32-C3 Super Mini | Microcontrôleur Wi-Fi, 5 V→3,3 V ; porte la WS2812 sur GPIO8 |
| **K1** | PhotoMOS G3VM-601AY2 (ou -601BY / AQY216) | Isolation galvanique 3,3 V ↔ 230 V, **≥ 400 V** |
| **PS1** | Module AC/DC TSP-05 (5 V / 3 W) | Alimentation à partir de L_F + N |
| **R1** | 330 Ω | Résistance de limitation de la LED de K1 (~6 mA) |
| **C1 / C2** | 220 µF / 100 nF | Tampon 5 V (pics Wi-Fi) + découplage |
| **F1** | 1 A temporisé, 5×20 mm | fusible fin côté primaire (X1→F1→L_F) |
| **RV1** | Varistance S14K275 | Protection contre les surtensions entre L_F et N |
| **SW1–3** | Boutons 6×6 mm | les trois boutons-poussoirs (position fixe, façade) |

## Le firmware

Le firmware est un projet **ESPHome** (`firmware/timer-relais-c3.yaml`)
avec ses propres extensions C++. Nom de l'appareil/hôte :
**`feeder-relais`** (→ `http://feeder-relais.local`).

- **Logique de minuterie :** trois durées indépendantes (1–600 s),
  modifiables via le web en cours de fonctionnement ; une pression brève
  démarre, une pression longue sur UP arrête tout.
- **Application web mobile et API JSON propres**
  (`firmware/timer_web.h`) sur le port 80 — aucun service cloud. Points
  d'accès : `/api/status`, `/api/trigger`, `/api/stop`, `/api/config`,
  `/api/net`, `/api/wifi`, `/api/reboot`.
- **Affichage OLED** (SSD1306 128×32) : réception Wi-Fi, grande horloge
  NTP, date, mémoire libre ; pendant la minuterie, le compte à rebours en
  secondes. Affichage pivoté à 180° (adapté à la position de montage).
- **Voyant d'état** via la WS2812 embarquée (GPIO8) : **vert** = prêt,
  **jaune** = minuterie en cours, **rouge** = anomalie.
- **Configuration réseau en temps réel** (`firmware/net_config.h`) : mode
  IP DHCP/statique, serveur NTP, nom d'hôte, itinérance 802.11k/v.
- **Multilingue** (web + OLED) : allemand / anglais / français,
  commutable pour tout l'appareil.
- **Provisioning par portail captif** — aucun mot de passe Wi-Fi compilé en
  dur ; les identifiants survivent à une mise à jour.
- **Mises à jour sans fil (OTA)** via la plateforme `web_server`
  (`POST /update`), ainsi qu'un tampon circulaire de journal/débogage
  (`/api/log`).

Des images de flashage prêtes (factory + OTA) se trouvent sous
`firmware/build/`.

## Utilisation

**Sur l'appareil** — trois boutons :

| Bouton | court | long |
|---|---|---|
| **S1** Down/Manual | déclencher la minuterie 1 | — |
| **S2** SET | déclencher la minuterie 2 | ≥ 3 s : menu d'info (naviguer avec S1/S3) |
| **S3** UP | déclencher la minuterie 3 | ≥ 1,2 s : arrêter toutes les minuteries |

**Mobile** — dans le navigateur `http://feeder-relais.local` : déclencher
une minuterie, régler les trois durées, consulter les valeurs réseau et
d'état, choisir la langue.

## Le boîtier (impression 3D)

Le boîtier se compose de la **partie avant** existante (façade d'origine
avec vitre et poussoirs) et d'une **partie arrière** imprimée soi-même :

- Source `box/feeder_back.scad` (OpenSCAD), STL prêt
  `box/feeder_back_35mm.stl`.
- **35 mm de profondeur** (au lieu des 5,7 mm d'origine), afin que la carte
  *et* le Shelly y trouvent leur place.
- Six colonnettes de vissage (pas 45 × 70 mm), patte de suspension à trou
  en serrure.
- `box/Timer-Ersatzplatine-v3-BOARD.stl` est une **maquette 1:1** de la
  carte — à imprimer à plat et à poser à l'intérieur pour vérifier
  l'ajustement **avant** de commander la vraie carte.

## Intégration avec ioBroker

Le Feeder-Relais constitue le **côté matériel** d'un distributeur de
nourriture automatique et s'intègre bien dans une domotique :

- Le **Shelly 1PM Mini Gen4 externe** s'intègre nativement dans ioBroker
  via l'**adaptateur Shelly** — l'état de commutation et la mesure de
  puissance y sont directement visibles et pilotables.
- La **propre API JSON** de l'appareil
  (`/api/status | trigger | stop | config`) peut être lue et pilotée par
  REST/script (par ex. `simple-api`, adaptateur JavaScript) — pour
  déclencher la minuterie et interroger l'état.

Dans le même environnement « Smart-Pond/Feeder », il existe deux
adaptateurs correspondants du même auteur, qui constituent le **côté
logiciel** :

- **[ioBroker.automatic-feeder](https://github.com/ssbingo/ioBroker.automatic-feeder)**
  — planification horaire, modèle de température, lever/coucher du soleil,
  pauses et notifications pour un distributeur de nourriture pour
  poissons/koïs/bassin.
- **[ioBroker.vis-2-widgets-automatic-feeder](https://github.com/ssbingo/ioBroker.vis-2-widgets-automatic-feeder)**
  — widgets de tableau de bord vis-2 prêts à l'emploi (vue en direct et
  télécommande) pour l'adaptateur ci-dessus.

Ainsi, le matériel (cet appareil + le Shelly), associé aux deux
adaptateurs, forme une chaîne continue depuis le bouton jusqu'au tableau de
bord.

## Reproduction et manuel

Un **manuel complet, accessible aux débutants**, guide pas à pas de la
carte vierge à l'appareil fini — avec sécurité, liste d'achats,
fabrication de la carte, soudure des composants, flashage du firmware et
mise en service, avec un sommaire cliquable :

**➡️ [docs/fr/Feeder-Relais-Manuel.pdf](docs/fr/Feeder-Relais-Manuel.pdf)**
(traductions : voir le [tableau des langues](#-sprachen--languages) ci-dessus.)

Flasher le firmware (ESP via USB-C) :

```bash
esphome run firmware/timer-relais-c3.yaml
```

## Structure du projet

```
kicad-v3/     carte v3 (KiCad : schéma, routage, règle des 6 mm, empreintes, modèles 3D)
box/          partie arrière du boîtier (source OpenSCAD + STL) et maquette de la carte
firmware/     firmware ESPHome (.yaml + .h), images de flashage prêtes dans build/
docs/         PDF du manuel (allemand) et traductions sous docs/<langue>/
README.md     ce document (allemand ; traductions sous docs/<langue>/)
```

## Statut

**Version 3 entièrement développée — avant la fabrication.** Carte routée
en 4 couches (DRC sans erreur réelle), carte et firmware alignés
(OLED-SDA sur GPIO7), boîtier et documentation terminés. Restant à
faire : régénérer les fichiers Gerber, essayage de la maquette, commande
en 4 couches, montage et test fonctionnel.

## Licence

Ce projet (matériel, firmware, boîtier et documentation) est placé sous la
licence **Creative Commons Attribution – Pas d'utilisation commerciale –
Partage dans les mêmes conditions 4.0 International (CC BY-NC-SA 4.0)**.

© 2026 Silvio Sternitzke

Vous êtes libre de :

- **Partager** — reproduire et redistribuer le matériel,
- **Adapter** — le remixer et vous en inspirer,

selon les conditions suivantes :

- **Attribution (BY)** — vous devez créditer l'auteur, fournir un lien vers
  la licence et indiquer si des modifications ont été apportées.
- **Pas d'utilisation commerciale (NC)** — non destiné à des fins
  commerciales.
- **Partage dans les mêmes conditions (SA)** — les adaptations doivent être
  diffusées sous la même licence.
- **Pas de restrictions supplémentaires** — vous n'êtes pas autorisé(e) à
  appliquer des clauses juridiques ou des mesures techniques qui
  restreindraient légalement autrui à faire ce que la licence autorise.

Texte de la licence :
<https://creativecommons.org/licenses/by-nc-sa/4.0/deed.fr> · texte
juridique complet dans [LICENSE](LICENSE).

> **Avertissement :** la reproduction se fait sous votre propre
> responsabilité. 230 volts sont mortels. Le matériel est fourni sans
> aucune garantie ; toute responsabilité pour des dommages est exclue. En
> cas de doute, faites appel à un(e) électricien(ne) qualifié(e).

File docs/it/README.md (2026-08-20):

# Feeder-Relais Logo Feeder-Relais

<p align="center">
  <a href="https://www.buymeacoffee.com/ssbingo">Buy me a coffee</a>
</p>

> **Origine:** Questo progetto è la conversione di un **SuperFish / Koi-Pro Fish Feeder** (mangiatoia automatica di Aquadistri — [gamma prodotti](https://aquadistri.com/de/brands/koi-pro/einrichtung-zubehoer/zubehoer/) · [manuale originale (PDF)](../Koi-Pro-FishFeeder-Original-Manual.pdf)) — sostituisce la scheda timer originale difettosa. **Il retro del contenitore e la scheda seguono le dimensioni del controller originale**, così entrambi entrano esattamente nell’alloggiamento esistente.

**Centralina timer 230 V da autocostruire — ESP32-C3 · OLED · PhotoMOS · Shelly 1PM Mini Gen4 esterno**

Il Feeder-Relais è una scheda di controllo autocostruita che accende un carico
a 230 volt alla pressione di un pulsante per un **tempo impostabile** e poi si
spegne da sola. Il nome deriva dall'impiego originario: sostituisce la scheda
timer difettosa di un **distributore automatico di mangime** (in inglese
*feeder*). Poiché in sostanza si limita a «premere un interruttore per un
certo tempo», si presta a qualsiasi carico che debba essere commutato in modo
temporizzato — pompa, motore del mangime, ventola, luce.

Tre pulsanti attivano tre tempi impostabili separatamente (valore predefinito
5/10/15 s), un display OLED mostra Wi-Fi, ora e conto alla rovescia, e
un'interfaccia web ottimizzata per smartphone consente l'uso e la
configurazione nella rete domestica — **senza app e senza cloud**. La
commutazione vera e propria e la misura della potenza sono affidate a uno
**Shelly 1PM Mini Gen4 esterno**; la scheda pilota il suo ingresso SW tramite
un **relè PhotoMOS con isolamento galvanico**. Grazie a questo, la funzione
principale è **indipendente dal Wi-Fi**.

> ### ⚠️ 230 volt — Pericolo di morte
> La tensione di rete può essere letale. La realizzazione, il collaudo e la
> messa in servizio del lato a 230 V vanno affidati a un **elettricista
> qualificato** o a una persona istruita. Tutti i test possibili senza
> personale qualificato avvengono in questo manuale **esclusivamente via USB
> e senza alcuna tensione di rete**. Leggere prima il capitolo 2 del manuale.

---

## 🌍 Sprachen · Languages

| Sprache | README | Handbuch (PDF) | 🌐 Online |
|---|---|---|---|
| 🇩🇪 **Deutsch** (Original) | [README.md](README.md) | [docs/handbuch/Feeder-Relais-Handbuch.pdf](docs/handbuch/Feeder-Relais-Handbuch.pdf) | [Online](https://ssbingo.github.io/timer-ersatzplatine/) |
| 🇬🇧 English | [docs/en/README.md](docs/en/README.md) | [docs/en/Feeder-Relais-Manual.pdf](docs/en/Feeder-Relais-Manual.pdf) | [Online](https://ssbingo.github.io/timer-ersatzplatine/en.html) |
| 🇫🇷 Français | [docs/fr/README.md](docs/fr/README.md) | [docs/fr/Feeder-Relais-Manuel.pdf](docs/fr/Feeder-Relais-Manuel.pdf) | [Online](https://ssbingo.github.io/timer-ersatzplatine/fr.html) |
| 🇳🇱 Nederlands | [docs/nl/README.md](docs/nl/README.md) | [docs/nl/Feeder-Relais-Handleiding.pdf](docs/nl/Feeder-Relais-Handleiding.pdf) | [Online](https://ssbingo.github.io/timer-ersatzplatine/nl.html) |
| 🇪🇸 Español | [docs/es/README.md](docs/es/README.md) | [docs/es/Feeder-Relais-Manual.pdf](docs/es/Feeder-Relais-Manual.pdf) | [Online](https://ssbingo.github.io/timer-ersatzplatine/es.html) |
| 🇮🇹 Italiano | [docs/it/README.md](docs/it/README.md) | [docs/it/Feeder-Relais-Manuale.pdf](docs/it/Feeder-Relais-Manuale.pdf) | [Online](https://ssbingo.github.io/timer-ersatzplatine/it.html) |

---

## Indice

1. [Panoramica](#panoramica)
2. [La catena di segnale](#la-catena-di-segnale)
3. [La scheda (hardware v3)](#la-scheda-hardware-v3)
4. [Il firmware](#il-firmware)
5. [Utilizzo](#utilizzo)
6. [L'involucro (stampa 3D)](#linvolucro-stampa-3d)
7. [Integrazione con ioBroker](#integrazione-con-iobroker)
8. [Autocostruzione e manuale](#autocostruzione-e-manuale)
9. [Struttura del progetto](#struttura-del-progetto)
10. [Stato](#stato)
11. [Licenza](#licenza)

---

## Panoramica

Il dispositivo sostituisce una scheda timer originale dietro un pannello
frontale esistente. È composto da quattro moduli ben separabili:

- **Scheda** (`kicad-v3/`) — ESP32-C3, alimentatore, PhotoMOS e i morsetti a
  230 V, quattro strati, tutta l'elettronica sul retro.
- **Firmware** (`firmware/`) — progetto ESPHome con una propria app web
  mobile, interfaccia JSON, orologio NTP, display OLED, LED di stato e
  interfaccia multilingue.
- **Involucro** (`box/`) — parte posteriore stampata in 3D (35 mm di
  profondità) che accoglie la scheda *e* lo Shelly esterno; la parte
  anteriore è il pannello frontale esistente.
- **Shelly 1PM Mini Gen4 esterno** — il relè di commutazione certificato con
  misura della potenza, cablato al di fuori della scheda.

La **divisione dei compiti** è il cuore del concetto: l'ESP misura il tempo e
invia allo Shelly un segnale hardware isolato galvanicamente; lo Shelly
commuta il carico e ne misura la potenza. Se il Wi-Fi si interrompe,
pulsanti, timer e commutazione continuano comunque a funzionare — solo il
comando remoto resta fermo.

## La catena di segnale

Dalla pressione del pulsante al carico commutato, il segnale attraversa
cinque stazioni, ciascuna con un solo compito:

```
Tasto  ─►  ESP32-C3  ─►  330 Ω  ─►  PhotoMOS  ─►  Shelly 1PM  ─►  Carico
S1–S3      misura il     limita     isola          commuta e        (pompa,
           tempo,        corrente   galvanica-      misura la         motore
           pilota        del LED    mente           potenza           mangime,
           l'OLED                                   230 V             luce …)
```

L'ESP lavora con i 3,3 V innocui e non deve mai toccare direttamente i
230 V. Il **PhotoMOS** è il ponte: separa completamente bassa tensione e
tensione di rete tramite la *luce*. Lo Shelly viene impostato su
**Switch/Follow** — il suo relè resta acceso esattamente per tutto il tempo
in cui è presente il nostro segnale; l'intera temporizzazione resta all'ESP.

## La scheda (hardware v3)

L'attuale versione 2 è disponibile come progetto KiCad completo in
`kicad-v3/`.

- **Dimensioni esterne** 101,6 × 77,5 mm, **quattro strati** (1,6 mm).
- **Tutta l'elettronica sul retro** — davanti restano solo i tre pulsanti e
  il connettore OLED (tutto ciò che si usa o si vede).
- I due **strati interni sono piani di massa continui** nella zona a bassa
  tensione → poche interferenze, Wi-Fi stabile.
- **Tensione di rete solo esterna:** le cinque reti a 230 V si trovano
  esclusivamente sugli strati esterni, in basso a sinistra, in una classe di
  rete propria con piste più larghe.
- **Distanza di dispersione di 6 mm** tra ogni rete a 230 V e ogni bassa
  tensione — definita come regola di verifica fissa in KiCad (`.kicad_dru`).
  L'unica eccezione è il PhotoMOS K1: il suo involucro *è* il punto di
  isolamento certificato.

### Assegnazione GPIO — corrispondenza vincolante scheda ↔ firmware

Questa assegnazione deve corrispondere esattamente su entrambi i lati,
altrimenti il dispositivo non funziona:

| Pin ESP | Firmware | Scheda / rete | Funzione |
|---|---|---|---|
| **GPIO3** | `btn_s1` (ingresso, pull-up, invertito) | Pad 3 → `/BTN1` | Pulsante **S1 Down/Manual** (T1) → Timer 1 |
| **GPIO4** | `btn_s2` | Pad 4 → `/BTN2` | Pulsante **S2 SET** (T2) → Timer 2 / pressione lunga: menu |
| **GPIO5** | `btn_s3` | Pad 5 → `/BTN3` | Pulsante **S3 UP** (T3) → Timer 3 / pressione lunga: Stop |
| **GPIO6** | `shelly_trigger` (uscita) | Pad 6 → `/PMOS_DRV` → R1 330 Ω → LED K1 | Pilotaggio PhotoMOS: HIGH = carico acceso |
| **GPIO7** | `i2c: sda` (400 kHz) | Pad 7 → `/SDA` → OLED J2.4 | Linea dati I²C verso l'OLED |
| **GPIO8** | `status_led` (WS2812, GRB) | interno al modulo (Pad 8 libero) | LED RGB di stato integrato (semaforo) |
| **GPIO9** | `i2c: scl` (400 kHz) | Pad 9 → `/SCL` → OLED J2.3 | Linea di clock I²C verso l'OLED (indirizzo 0x3C) |
| **5V / GND** | Alimentazione del modulo | `/+5V` / `GND` dall'alimentatore | Alimentazione + massa comune |
| **3V3** | Regolatore integrato | `/+3V3` → OLED-VCC | 3,3 V per l'OLED |

> **Importante:** SDA si trova intenzionalmente su **GPIO7**, non GPIO8 — su
> GPIO8 si trova il WS2812 integrato. Se lì ci fosse l'I²C, l'OLED
> rimarrebbe nero e il traffico dati disturberebbe il LED.

### Morsetti di collegamento e reti

| Morsetto | Collegamento | Assegnazione |
|---|---|---|
| **X1** | Ingresso rete | 1 = N, 2 = L_IN (230 V in ingresso) |
| **X2** | Uscita carico | 1 = O (commutato), 2 = N |
| **X3** | Snubber | 1 = O, 2 = N — rete RC opzionale per carichi induttivi |
| **J1** | Shelly (esterno) | 1 = SW, 2 = O, 3 = L, 4 = N |
| **J2** | OLED | GND / VCC / SCL / SDA (a innesto) |

Le cinque reti a 230 V della classe di rete «230V»: `L_IN` (non protetta,
X1→F1), `L_F` (protetta, F1→RV1/PS1/K1.3/Shelly-L), `N` (neutro),
`SW_SHELLY` (commutata, K1.4→Shelly-SW) e `O_LAST` (commutata,
Shelly-O→X2/X3).

### Componenti principali

| Sigla | Componente | Funzione |
|---|---|---|
| **U1** | ESP32-C3 Super Mini | Microcontrollore con Wi-Fi, 5 V→3,3 V; porta il WS2812 su GPIO8 |
| **K1** | PhotoMOS G3VM-601AY2 (o -601BY / AQY216) | Isolamento galvanico 3,3 V ↔ 230 V, **≥ 400 V** |
| **PS1** | Modulo AC/DC TSP-05 (5 V / 3 W) | Alimentatore da L_F + N |
| **R1** | 330 Ω | Resistenza di limitazione del LED di K1 (~6 mA) |
| **C1 / C2** | 220 µF / 100 nF | Buffer 5 V (picchi Wi-Fi) + disaccoppiamento |
| **F1** | 1 A ritardato, 5×20 mm | fusibile primario (X1→F1→L_F) |
| **RV1** | Varistore S14K275 | Protezione da sovratensione tra L_F e N |
| **SW1–3** | Pulsante 6×6 mm | i tre micropulsanti (posizione fissa, pannello frontale) |

## Il firmware

Il firmware è un progetto **ESPHome** (`firmware/timer-relais-c3.yaml`) con
estensioni C++ proprie. Nome del dispositivo/hostname: **`feeder-relais`**
(→ `http://feeder-relais.local`).

- **Logica del timer:** tre tempi indipendenti (1–600 s), modificabili via
  web durante il funzionamento; una pressione breve avvia, una pressione
  lunga su UP arresta tutto.
- **App web mobile propria + API JSON** (`firmware/timer_web.h`) sulla
  porta 80 — nessun servizio cloud. Endpoint: `/api/status`,
  `/api/trigger`, `/api/stop`, `/api/config`, `/api/net`, `/api/wifi`,
  `/api/reboot`.
- **Display OLED** (SSD1306 128×32): ricezione Wi-Fi, orologio NTP grande,
  data, memoria libera; durante il timer, il conto alla rovescia in
  secondi. Visualizzazione ruotata di 180° (adattata alla posizione di
  montaggio).
- **Semaforo di stato** tramite il WS2812 integrato (GPIO8): **verde** =
  pronto, **giallo** = timer in corso, **rosso** = anomalia.
- **Configurazione di rete a runtime** (`firmware/net_config.h`): modalità
  IP DHCP/statica, server NTP, hostname, roaming 802.11k/v.
- **Multilingue** (web + OLED): tedesco / inglese / francese, selezionabile
  per l'intero dispositivo.
- **Provisioning tramite captive portal** — nessuna password Wi-Fi
  compilata nel firmware; le credenziali sopravvivono a un aggiornamento.
- **Aggiornamenti via etere (OTA)** tramite la piattaforma `web_server`
  (`POST /update`), oltre a un buffer circolare di log/debug (`/api/log`).

Le immagini flash già pronte (factory + OTA) si trovano in
`firmware/build/`.

## Utilizzo

**Sul dispositivo** — tre pulsanti:

| Pulsante | breve | lungo |
|---|---|---|
| **S1** Down/Manual | Avvia Timer 1 | — |
| **S2** SET | Avvia Timer 2 | ≥ 3 s: menu informazioni (scorrere con S1/S3) |
| **S3** UP | Avvia Timer 3 | ≥ 1,2 s: arresta tutti i timer |

**Da mobile** — nel browser `http://feeder-relais.local`: avviare i timer,
impostare i tre tempi, consultare i valori di rete e di stato, scegliere la
lingua.

## L'involucro (stampa 3D)

L'involucro è composto dalla **parte anteriore** esistente (pannello
frontale originale con finestrella e pulsanti a stantuffo) e da una **parte
posteriore** stampata in proprio:

- Sorgente `box/feeder_back.scad` (OpenSCAD), file pronto
  `box/feeder_back_35mm.stl`.
- **Profondità 35 mm** (invece dei 5,7 mm originali), per far entrare
  scheda *e* Shelly.
- Sei colonnette filettate (passo 45 × 70 mm), linguetta di sospensione con
  foro a serratura.
- `box/Timer-Ersatzplatine-v3-BOARD.stl` è una **sagoma in scala 1:1**
  della scheda — stamparla piatta e inserirla per verificare
  l'accoppiamento **prima** di ordinare la scheda vera.

## Integrazione con ioBroker

Il Feeder-Relais è il **lato hardware** di un distributore automatico di
mangime e si integra bene in un sistema di domotica:

- Lo **Shelly 1PM Mini Gen4 esterno** viene integrato in ioBroker in modo
  nativo tramite l'**adattatore Shelly** — stato di commutazione e misura
  della potenza sono direttamente visibili e controllabili.
- La **API JSON propria** del dispositivo (`/api/status | trigger | stop |
  config`) può essere letta e comandata via REST/script (ad es.
  `simple-api`, adattatore JavaScript) — per l'avvio dei timer e
  l'interrogazione dello stato.

Nello stesso ambito «Smart-Pond/Feeder» esistono due adattatori dello
stesso autore che costituiscono il **lato software**:

- **[ioBroker.automatic-feeder](https://github.com/ssbingo/ioBroker.automatic-feeder)**
  — pianificazione oraria, modello di temperatura, alba/tramonto, pause e
  notifiche per un distributore automatico di mangime per pesci/koi/laghetto.
- **[ioBroker.vis-2-widgets-automatic-feeder](https://github.com/ssbingo/ioBroker.vis-2-widgets-automatic-feeder)**
  — widget dashboard vis-2 già pronti (vista in tempo reale e comando
  remoto) per l'adattatore sopra indicato.

In questo modo l'hardware (questo dispositivo + Shelly), insieme ai due
adattatori, forma una catena continua dal pulsante alla dashboard.

## Autocostruzione e manuale

Un **manuale completo, adatto ai principianti** guida passo dopo passo
dalla scheda vuota al dispositivo finito — con sicurezza, lista della
spesa, produzione della scheda, montaggio dei componenti, flashing del
firmware e messa in servizio, con indice cliccabile incluso:

**➡️ [docs/it/Feeder-Relais-Manuale.pdf](docs/it/Feeder-Relais-Manuale.pdf)**
(per le altre lingue vedi la [tabella delle lingue](#-sprachen--languages)
qui sopra.)

Flashing del firmware (ESP via USB-C):

```bash
esphome run firmware/timer-relais-c3.yaml
```

## Struttura del progetto

```
kicad-v3/     Scheda v3 (KiCad: schema elettrico, layout, regola dei 6 mm, footprint, modelli 3D)
box/          Parte posteriore dell'involucro (sorgente OpenSCAD + STL) e sagoma della scheda
firmware/     Firmware ESPHome (.yaml + .h), immagini flash già pronte in build/
docs/         PDF del manuale (tedesco) e traduzioni in docs/<lingua>/
README.md     questo documento (tedesco; traduzioni in docs/<lingua>/)
```

## Stato

**Versione 2 con sviluppo completato — prima della produzione.** Scheda
instradata a 4 strati (DRC senza errori reali), scheda e firmware allineati
(OLED-SDA su GPIO7), involucro e documentazione completi. Da fare:
rigenerare i Gerber, prova di accoppiamento della sagoma, ordine a 4
strati, montaggio e collaudo funzionale.

## Licenza

Questo progetto (hardware, firmware, involucro e documentazione) è
distribuito con la licenza **Creative Commons Attribuzione – Non
commerciale – Condividi allo stesso modo 4.0 Internazionale (CC
BY-NC-SA 4.0)**.

© 2026 Silvio Sternitzke

Sei libero di:

- **Condividere** — riprodurre e ridistribuire il materiale con qualsiasi
  mezzo e formato,
- **Modificare** — remixare, trasformare il materiale e crearne altri a
  partire da esso,

alle seguenti condizioni:

- **Attribuzione (BY)** — devi indicare l'autore, fornire un link alla
  licenza e segnalare se sono state effettuate modifiche.
- **Non commerciale (NC)** — non puoi utilizzare il materiale per scopi
  commerciali.
- **Condividi allo stesso modo (SA)** — se remixi, trasformi o sviluppi il
  materiale, devi distribuire i tuoi contributi con la stessa licenza
  dell'originale.
- **Nessuna restrizione aggiuntiva** — non puoi applicare termini legali o
  misure tecnologiche che impediscano legalmente ad altri di fare ciò che
  la licenza consente.

Testo della licenza:
<https://creativecommons.org/licenses/by-nc-sa/4.0/deed.it> · per il testo
legale completo vedi [LICENSE](LICENSE).

> **Esclusione di responsabilità:** l'autocostruzione avviene sotto la
> propria responsabilità. 230 volt sono pericolosi per la vita. Il
> materiale viene fornito senza alcuna garanzia; è esclusa qualsiasi
> responsabilità per danni. In caso di dubbio, rivolgersi a un elettricista
> qualificato.

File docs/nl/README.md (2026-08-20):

# Feeder-Relais Logo Feeder-Relais

<p align="center">
  <a href="https://www.buymeacoffee.com/ssbingo">Buy me a coffee</a>
</p>

> **Herkomst:** Dit project is een ombouw van een **SuperFish / Koi-Pro Fish Feeder** (voederautomaat van Aquadistri — [productlijn](https://aquadistri.com/de/brands/koi-pro/einrichtung-zubehoer/zubehoer/) · [originele handleiding (PDF)](../Koi-Pro-FishFeeder-Original-Manual.pdf)) — het vervangt de defecte originele timerprint. **De achterkant van de behuizing en de print volgen de afmetingen van de originele besturing**, zodat beide precies in de bestaande behuizing passen.

**230V-timerbesturing om zelf te bouwen — ESP32-C3 · OLED · PhotoMOS · externe Shelly 1PM Mini Gen4**

Het Feeder-Relais is een zelfgebouwde stuurprintplaat die een 230-volt-last op
knopdruk voor een **instelbare tijd** inschakelt en daarna vanzelf weer
uitschakelt. De naam komt van de oorspronkelijke toepassing: het vervangt de
defecte tijdschakelprintplaat van een **voederautomaat** (Engels *feeder*).
Omdat het in de kern alleen „een schakelaar voor een bepaalde tijd indrukt”,
is het geschikt voor elke last die tijdgestuurd geschakeld moet worden — pomp,
voedermotor, ventilator, licht.

Drie drukknoppen activeren drie afzonderlijk instelbare tijden (standaard
5/10/15 s), een OLED toont wifi, tijd en de aftelling, en een voor mobiele
telefoons geoptimaliseerde webinterface maakt bediening en configuratie in
het thuisnetwerk mogelijk — **zonder app en zonder cloud**. Het eigenlijke
schakelen en het meten van het vermogen gebeurt door een **externe Shelly
1PM Mini Gen4**; de printplaat stuurt de SW-ingang daarvan **galvanisch
gescheiden** aan via een **PhotoMOS-relais**. Daardoor is de kernfunctie
**wifi-onafhankelijk**.

> ### ⚠️ 230 volt — levensgevaar
> Netspanning kan dodelijk zijn. Opbouw, controle en inbedrijfstelling van de
> 230-V-zijde horen in handen van een **elektromonteur** of een onderrichte
> persoon. Alle tests die zonder vakman mogelijk zijn, verlopen **uitsluitend
> via USB en zonder enige netspanning**. Lees eerst hoofdstuk 2 van de
> handleiding.

---

## 🌍 Sprachen · Languages

| Sprache | README | Handbuch (PDF) | 🌐 Online |
|---|---|---|---|
| 🇩🇪 **Deutsch** (Original) | [README.md](README.md) | [docs/handbuch/Feeder-Relais-Handbuch.pdf](docs/handbuch/Feeder-Relais-Handbuch.pdf) | [Online](https://ssbingo.github.io/timer-ersatzplatine/) |
| 🇬🇧 English | [docs/en/README.md](docs/en/README.md) | [docs/en/Feeder-Relais-Manual.pdf](docs/en/Feeder-Relais-Manual.pdf) | [Online](https://ssbingo.github.io/timer-ersatzplatine/en.html) |
| 🇫🇷 Français | [docs/fr/README.md](docs/fr/README.md) | [docs/fr/Feeder-Relais-Manuel.pdf](docs/fr/Feeder-Relais-Manuel.pdf) | [Online](https://ssbingo.github.io/timer-ersatzplatine/fr.html) |
| 🇳🇱 Nederlands | [docs/nl/README.md](docs/nl/README.md) | [docs/nl/Feeder-Relais-Handleiding.pdf](docs/nl/Feeder-Relais-Handleiding.pdf) | [Online](https://ssbingo.github.io/timer-ersatzplatine/nl.html) |
| 🇪🇸 Español | [docs/es/README.md](docs/es/README.md) | [docs/es/Feeder-Relais-Manual.pdf](docs/es/Feeder-Relais-Manual.pdf) | [Online](https://ssbingo.github.io/timer-ersatzplatine/es.html) |
| 🇮🇹 Italiano | [docs/it/README.md](docs/it/README.md) | [docs/it/Feeder-Relais-Manuale.pdf](docs/it/Feeder-Relais-Manuale.pdf) | [Online](https://ssbingo.github.io/timer-ersatzplatine/it.html) |

---

## Inhoud

1. [Overzicht](#overzicht)
2. [De signaalketen](#de-signaalketen)
3. [De printplaat (hardware v3)](#de-printplaat-hardware-v3)
4. [De firmware](#de-firmware)
5. [Bediening](#bediening)
6. [De behuizing (3D-print)](#de-behuizing-3d-print)
7. [Aansluiting op ioBroker](#aansluiting-op-iobroker)
8. [Nabouw & handleiding](#nabouw--handleiding)
9. [Projectstructuur](#projectstructuur)
10. [Status](#status)
11. [Licentie](#licentie)

---

## Overzicht

Het apparaat vervangt een originele timerprintplaat achter een bestaande
frontplaat. Het bestaat uit vier goed te scheiden bouwstenen:

- **Printplaat** (`kicad-v3/`) — ESP32-C3, voeding, PhotoMOS en de
  230-V-klemmen, vierlaags, alle elektronica op de achterzijde.
- **Firmware** (`firmware/`) — ESPHome-project met eigen mobiele webapp,
  JSON-interface, NTP-klok, OLED-weergave, statusled en meertalige
  bediening.
- **Behuizing** (`box/`) — 3D-geprint achterstuk (35 mm diep), dat printplaat
  *en* de externe Shelly opneemt; het voorstuk is de bestaande frontplaat.
- **Externe Shelly 1PM Mini Gen4** — het gecertificeerde schakelrelais met
  vermogensmeting, buiten de printplaat bedraad.

De **taakverdeling** vormt de kern van het concept: de ESP meet de tijd en
geeft een galvanisch gescheiden hardwaresignaal aan de Shelly; de Shelly
schakelt de last en meet het vermogen. Valt de wifi uit, dan blijven
knoppen, timer en schakelen gewoon werken — alleen de afstandsbediening
ligt stil.

## De signaalketen

Van de knopdruk tot de geschakelde last doorloopt het signaal vijf stations,
elk met precies één taak:

```
Knop   ─►  ESP32-C3  ─►  330 Ω  ─►  PhotoMOS  ─►  Shelly 1PM  ─►  Last
S1–S3      telt de       begrenst    schakelt      schakelt en      (pomp,
           tijd, tekent  de LED-     galvanisch    meet de          voeder-
           het OLED      stroom      gescheiden    230-V-last       motor …)
```

De ESP werkt met ongevaarlijke 3,3 V en mag 230 V nooit rechtstreeks
aanraken. De **PhotoMOS** is de brug: hij scheidt laag- en netspanning
volledig door *licht*. De Shelly wordt op **Switch/Follow** ingesteld — het
relais ervan staat precies zo lang aan als ons signaal actief is; de
volledige timing blijft bij de ESP.

## De printplaat (hardware v3)

De huidige versie 2 is klaar als KiCad-project onder `kicad-v3/`.

- **Buitenmaat** 101,6 × 77,5 mm, **vierlaags** (1,6 mm).
- **Alle elektronica op de achterzijde** — aan de voorzijde blijven alleen de
  drie drukknoppen en de OLED-connector (alles wat bediend of gezien wordt).
- De beide **binnenlagen zijn doorlopende massavlakken** in het
  laagspanningsgebied → storingsarm, stabiele wifi.
- **Netspanning alleen aan de buitenzijde:** de vijf 230-V-netten liggen
  uitsluitend op de buitenlagen, linksonder, in een eigen netklasse met
  bredere banen.
- **6-mm-kruipweg** tussen elk 230-V-net en elke laagspanning — vastgelegd
  als vaste KiCad-controleregel (`.kicad_dru`). Enige uitzondering is de
  PhotoMOS K1: de behuizing daarvan *is* het gecertificeerde scheidingspunt.

### GPIO-toewijzing — bindende afstemming printplaat ↔ firmware

Deze toewijzing moet aan beide kanten exact overeenkomen, anders werkt het
apparaat niet:

| ESP-pin | Firmware | Printplaat / net | Functie |
|---|---|---|---|
| **GPIO3** | `btn_s1` (ingang, pull-up, geïnverteerd) | Pad 3 → `/BTN1` | Drukknop **S1 Down/Manual** (T1) → timer 1 |
| **GPIO4** | `btn_s2` | Pad 4 → `/BTN2` | Drukknop **S2 SET** (T2) → timer 2 / lang: menu |
| **GPIO5** | `btn_s3` | Pad 5 → `/BTN3` | Drukknop **S3 UP** (T3) → timer 3 / lang: stop |
| **GPIO6** | `shelly_trigger` (uitgang) | Pad 6 → `/PMOS_DRV` → R1 330 Ω → K1-LED | PhotoMOS-driver: HIGH = last aan |
| **GPIO7** | `i2c: sda` (400 kHz) | Pad 7 → `/SDA` → OLED J2.4 | I²C-datalijn naar het OLED |
| **GPIO8** | `status_led` (WS2812, GRB) | module-intern (pad 8 vrij) | Onboard rgb-statusled (verkeerslicht) |
| **GPIO9** | `i2c: scl` (400 kHz) | Pad 9 → `/SCL` → OLED J2.3 | I²C-kloklijn naar het OLED (adres 0x3C) |
| **5V / GND** | Modulvoeding | `/+5V` / `GND` van de voeding | Voeding + gemeenschappelijke massa |
| **3V3** | Onboard-regelaar | `/+3V3` → OLED-VCC | 3,3 V voor het OLED |

> **Belangrijk:** SDA ligt bewust op **GPIO7**, niet GPIO8 — op GPIO8 zit de
> onboard WS2812. Lag I²C daar, dan zou het OLED zwart blijven en het
> dataverkeer de led verstoren.

### Aansluitklemmen en netten

| Klem | Aansluiting | Bezetting |
|---|---|---|
| **X1** | Netingang | 1 = N, 2 = L_IN (230 V binnenkomend) |
| **X2** | Lastafgang | 1 = O (geschakeld), 2 = N |
| **X3** | Snubber | 1 = O, 2 = N — optioneel RC-lid voor inductieve lasten |
| **J1** | Shelly (extern) | 1 = SW, 2 = O, 3 = L, 4 = N |
| **J2** | OLED | GND / VCC / SCL / SDA (opgestoken) |

De vijf 230-V-netten van de netklasse „230V": `L_IN` (onbeveiligd, X1→F1),
`L_F` (beveiligd, F1→RV1/PS1/K1.3/Shelly-L), `N` (nul), `SW_SHELLY`
(geschakeld, K1.4→Shelly-SW) en `O_LAST` (geschakeld, Shelly-O→X2/X3).

### Belangrijke componenten

| Aanduiding | Component | Functie |
|---|---|---|
| **U1** | ESP32-C3 Super Mini | Microcontroller met wifi, 5 V→3,3 V; draagt de WS2812 op GPIO8 |
| **K1** | PhotoMOS G3VM-601AY2 (of -601BY / AQY216) | Galvanische scheiding 3,3 V ↔ 230 V, **≥ 400 V** |
| **PS1** | AC/DC-module TSP-05 (5 V / 3 W) | Voeding uit L_F + N |
| **R1** | 330 Ω | Voorweerstand van de K1-led (~6 mA) |
| **C1 / C2** | 220 µF / 100 nF | 5-V-buffer (wifipieken) + afblokking |
| **F1** | 1 A traag, 5×20 mm | fijnzekering aan de primaire zijde (X1→F1→L_F) |
| **RV1** | Varistor S14K275 | Overspanningsbeveiliging tussen L_F en N |
| **SW1–3** | Drukknop 6×6 mm | de drie korteslagdrukknoppen (positie vast, frontplaat) |

## De firmware

De firmware is een **ESPHome**-project (`firmware/timer-relais-c3.yaml`) met
eigen C++-uitbreidingen. Apparaatnaam/hostnaam: **`feeder-relais`**
(→ `http://feeder-relais.local`).

- **Timerlogica:** drie onafhankelijke tijden (1–600 s), tijdens bedrijf via
  het web te wijzigen; korte druk op de knop start, lange druk op UP stopt
  alles.
- **Eigen mobiele webapp + JSON-API** (`firmware/timer_web.h`) op poort 80 —
  geen clouddienst. Endpoints: `/api/status`, `/api/trigger`, `/api/stop`,
  `/api/config`, `/api/net`, `/api/wifi`, `/api/reboot`.
- **OLED-weergave** (SSD1306 128×32): wifi-ontvangst, grote NTP-klok, datum,
  vrij geheugen; tijdens de timerloop de secondenaftelling. Weergave 180°
  gedraaid (aangepast aan de inbouwpositie).
- **Statusverkeerslicht** via de onboard WS2812 (GPIO8): **groen** = klaar,
  **geel** = timer loopt, **rood** = storing.
- **Netwerkconfiguratie tijdens bedrijf** (`firmware/net_config.h`): IP-modus
  DHCP/statisch, NTP-server, hostnaam, 802.11k/v-roaming.
- **Meertalig** (web + OLED): Duits / Engels / Frans, apparaatbreed
  omschakelbaar.
- **Provisioning via captive portal** — geen wifiwachtwoord ingecompileerd;
  de toegangsgegevens overleven een update.
- **Draadloze updates (OTA)** via het `web_server`-platform (`POST /update`)
  plus een log-/debug-ringbuffer (`/api/log`).

Kant-en-klare flashimages (factory + OTA) staan onder `firmware/build/`.

## Bediening

**Op het apparaat** — drie drukknoppen:

| Knop | kort | lang |
|---|---|---|
| **S1** Down/Manual | Timer 1 activeren | — |
| **S2** SET | Timer 2 activeren | ≥ 3 s: info-menu (bladeren met S1/S3) |
| **S3** UP | Timer 3 activeren | ≥ 1,2 s: alle timers stoppen |

**Mobiel** — in de browser `http://feeder-relais.local`: timer activeren, de
drie tijden instellen, netwerk- en statuswaarden bekijken, taal kiezen.

## De behuizing (3D-print)

De behuizing bestaat uit het bestaande **voorstuk** (originele frontplaat met
kijkvenster en druktaster-stoterpennen) en een zelf geprint **achterstuk**:

- Bron `box/feeder_back.scad` (OpenSCAD), kant-en-klare `box/feeder_back_35mm.stl`.
- **35 mm diep** (in plaats van de originele 5,7 mm), zodat printplaat *en*
  Shelly erin passen.
- Zes schroefdomes (raster 45 × 70 mm), ophanglipje met sleutelgat.
- `box/Timer-Ersatzplatine-v3-BOARD.stl` is een **1:1-attrappe** van de
  printplaat — plat printen en erin leggen om de pasvorm te controleren,
  **voordat** de echte printplaat wordt besteld.

## Aansluiting op ioBroker

Het Feeder-Relais is de **hardwarezijde** van een voederautomaat en laat zich
goed inbinden in een huisautomatisering:

- De **externe Shelly 1PM Mini Gen4** wordt in ioBroker via de
  **Shelly-adapter** native ingebonden — schakeltoestand en vermogensmeting
  zijn daar direct zichtbaar en bestuurbaar.
- De **eigen JSON-API** van het apparaat (`/api/status | trigger | stop |
  config`) is via REST/script (bijv. `simple-api`, JavaScript-adapter) uit
  te lezen en te bedienen — voor het activeren van timers en het opvragen
  van de status.

In dezelfde „Smart-Pond/Feeder"-omgeving zijn er twee passende adapters van
dezelfde auteur, die de **softwarezijde** vormen:

- **[ioBroker.automatic-feeder](https://github.com/ssbingo/ioBroker.automatic-feeder)**
  — planning, temperatuurmodel, zonsopgang/-ondergang, pauzes en
  meldingen voor een vis-/koi-/vijvervoederautomaat.
- **[ioBroker.vis-2-widgets-automatic-feeder](https://github.com/ssbingo/ioBroker.vis-2-widgets-automatic-feeder)**
  — kant-en-klare vis-2-dashboardwidgets (live weergave en
  afstandsbediening) voor bovenstaande adapter.

Zo vormt de hardware (dit apparaat + Shelly) samen met de twee adapters een
doorlopende keten van de knop tot het dashboard.

## Nabouw & handleiding

Een **volledige, voor beginners geschikte handleiding** leidt je stap voor
stap van de lege printplaat tot het kant-en-klare apparaat — met
veiligheid, inkooplijst, printplaatproductie, montage, firmware flashen en
inbedrijfstelling, inclusief klikbare inhoudsopgave:

**➡️ [docs/nl/Feeder-Relais-Handleiding.pdf](docs/nl/Feeder-Relais-Handleiding.pdf)**
(voor andere talen zie de [talentabel](#-sprachen--languages) hierboven.)

Firmware flashen (ESP via USB-C):

```bash
esphome run firmware/timer-relais-c3.yaml
```

## Projectstructuur

```
kicad-v3/     Printplaat v3 (KiCad: schema, layout, 6-mm-regel, footprints, 3D-modellen)
box/          Behuizing-achterstuk (OpenSCAD-bron + STL) en printplaat-attrappe
firmware/     ESPHome-firmware (.yaml + .h), kant-en-klare flashimages in build/
docs/         Handleiding-PDF (Duits) en vertalingen onder docs/<taal>/
README.md     dit document (Duits; vertalingen onder docs/<taal>/)
```

## Status

**Versie 2 volledig ontwikkeld — vóór de productie.** Printplaat 4-laags
gerouteerd (DRC zonder echte fouten), board ↔ firmware afgestemd (OLED-SDA
op GPIO7), behuizing en documentatie klaar. Nog te doen: Gerberbestanden
opnieuw genereren, pasproef van de attrappe, bestelling van de 4 lagen,
opbouw en functietest.

## Licentie

Dit project (hardware, firmware, behuizing en documentatie) staat onder de
licentie **Creative Commons Naamsvermelding – Niet-commercieel – Gelijk
delen 4.0 Internationaal (CC BY-NC-SA 4.0)**.

© 2026 Silvio Sternitzke

Het staat je vrij om:

- **Te delen** — het materiaal te kopiëren en verder te verspreiden,
- **Te bewerken** — het te hervormen en erop voort te bouwen,

onder de volgende voorwaarden:

- **Naamsvermelding (BY)** — vermeld de maker, koppel naar de licentie en
  geef aan of er wijzigingen zijn aangebracht.
- **Niet-commercieel (NC)** — niet voor commerciële doeleinden.
- **Gelijk delen (SA)** — bewerkingen moeten onder dezelfde licentie worden
  verspreid.
- **Geen aanvullende restricties** — geen extra clausules of technische
  maatregelen die anderen iets wettelijk toegestaans ontzeggen.

Licentietekst: <https://creativecommons.org/licenses/by-nc-sa/4.0/deed.nl> ·
volledige juridische tekst zie [LICENSE](LICENSE).

> **Aansprakelijkheidsuitsluiting:** de nabouw gebeurt op eigen
> verantwoordelijkheid. 230 volt is levensgevaarlijk. Het materiaal wordt
> zonder garantie beschikbaar gesteld; alle aansprakelijkheid voor schade
> is uitgesloten. Raadpleeg bij twijfel een elektromonteur.
</content>

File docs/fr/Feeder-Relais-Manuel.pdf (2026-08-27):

ESP32-C3 · Wi-Fi | Minuterie 230 V | Shelly 1PM Mini Gen4

Fait maison · Version 3

# Feeder-Relais

## Le manuel — de la carte vierge à l'appareil fini dans son boîtier

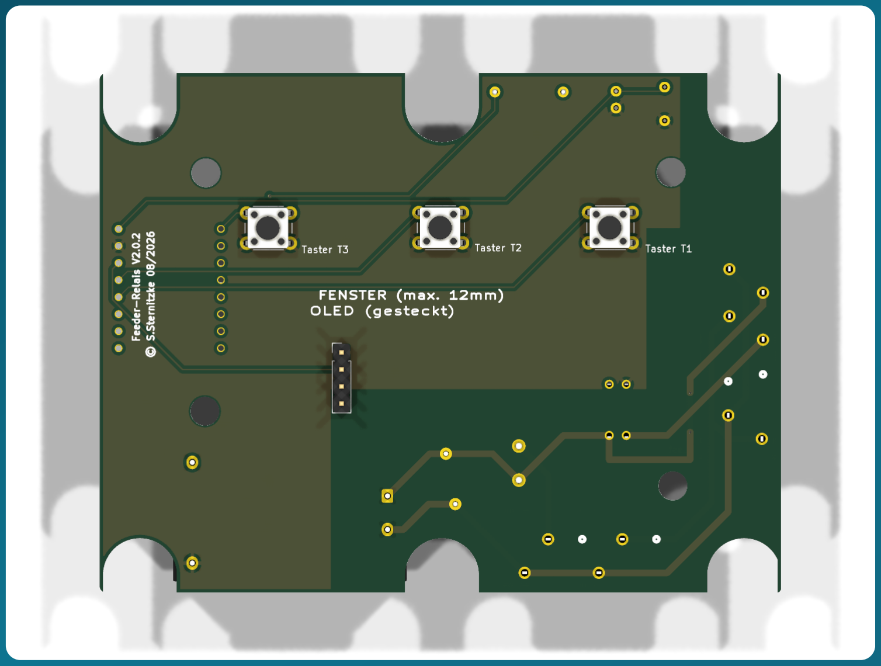
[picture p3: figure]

Édition 1 · août 2026 · français | Matériel v3 · firmware ESPHome · CC BY-NC-SA 4.0

# À propos de ce manuel

Ce manuel s'adresse aux débutantes et débutants. Vous n'avez besoin d'aucune formation en électronique — mais d'un fer à souder, d'un peu de patience et de la volonté de taper quelques commandes dans un terminal. Chaque étape est décrite intégralement : ce que vous faites, pourquoi vous le faites, et comment reconnaître que cela a fonctionné. À la fin, vous tiendrez entre les mains un appareil qui met sous tension une charge 230 V (par exemple un distributeur de nourriture automatique) sur simple pression d'un bouton, pendant une durée réglable — utilisable via trois boutons, un petit écran et une page web sur le réseau domestique.

Cet appareil est sous 230 volts
230 volts de tension secteur peuvent être mortels. Le montage, le contrôle et la mise en service de l'alimentation doivent être confiés à un(e) électricien(ne) qualifié(e) ou à une personne formée et habilitée. Tous les tests réalisables sans professionnel se déroulent dans ce manuel exclusivement via USB et sans aucune tension secteur. Merci de lire d'abord le chapitre 2.

Comment lire ce manuel

ℹ Remarque
Les encadrés bleus apportent des connaissances de base. On peut les ignorer — mais ils rendent bien des choses plus compréhensibles.

✓ Astuce
Les encadrés verts vous font gagner du temps ou des nerfs.

⚠ Attention
Les encadrés jaunes signalent les endroits où les choses tournent souvent mal.

Stop
Les encadrés rouges signalent des manipulations pouvant détruire le matériel ou vous blesser. À lire impérativement.

Les commandes pour le terminal se présentent ainsi — elles se saisissent ligne par ligne et se
valident avec | Entrée . Les lignes qui commencent par | # | sont des commentaires et ne doivent
pas être tapées :
© 2026 S. Sternitzke · CC BY-NC-SA 4.0 | ↑ Sommaire | Feeder-Relais · Manuel Édition 1

# Ceci est un commentaire — juste pour l'explication

esphome run firmware/timer-relais-c3.yaml

Les renvois tels que « chapitre 7 » sont cliquables dans le PDF. Le lien « ↑ Sommaire » en bas de chaque page vous permet à tout moment de revenir à la vue d'ensemble.

# Sommaire

### 1 Ce qu'est le Feeder-Relais

### 2 Sécurité — à lire en premier

### 3 Comment fonctionne le système

### 4 Liste d'achats : matériel et outillage

### 5 Le boîtier

### 6 Comprendre la carte

### 7 Faire fabriquer la carte

### 8 KiCad pas à pas (uniquement en cas de modifications personnelles)

### 9 Souder les composants sur la carte

### 10 Installer le firmware

### 11 Configurer le Wi-Fi et piloter depuis le navigateur

### 12 Réseau, langue et affichage

### 13 Raccorder le Shelly externe

### 14 Assemblage et mise en service

### 15 Mises à jour du firmware et maintenance

### 16 Dépannage

### 17 Annexe : brochages, fichiers, glossaire

# 1 Ce qu'est le Feeder-Relais

Le Feeder-Relais est une carte de commande faite maison qui met sous tension une charge 230 volts sur simple pression d'un bouton, pendant une durée réglable, puis la coupe automatiquement. Son nom vient de son usage d'origine : elle remplace la carte de programmation horaire défectueuse d'un distributeur de nourriture automatique (feeder en anglais). Comme elle se contente en définitive d'« actionner un interrupteur pendant un certain temps », elle convient à toute charge que l'on souhaite commander de façon temporisée.

## 1.1 Ce que fait l'appareil

Trois boutons-poussoirs se trouvent en façade. Une pression brève met la charge sous tension pour une durée préréglée :

Bouton | Étiquette | Durée par défaut | réglable
S1 | Down / Manual (T1) | 5 secondes | 1–600 s via Wi-Fi
S2 | SET (T2) | 10 secondes | 1–600 s via Wi-Fi
S3 | UP (T3) | 15 secondes | 1–600 s via Wi-Fi

Un petit écran OLED derrière la vitre de protection affiche en haut la réception Wi-Fi, l'heure en grand (réglée via un serveur de temps Internet) et l'état Repos ; en bas la date et la mémoire libre. Lorsqu'une minuterie est en cours, le compte à rebours en secondes s'affiche au centre et Repas à droite.

La commande fonctionne sans application et sans cloud, via une petite page web optimisée pour mobile que l'ESP32 fournit lui-même (dans le navigateur : http://feeder-relais.local ) : déclencher une minuterie, régler les durées, consulter les valeurs réseau et d'état. Pour le raccordement à une domotique (par exemple ioBroker ou Home Assistant), il existe en plus une interface JSON légère (chapitre 11).

## 1.2 La chaîne de signal

De la pression du bouton jusqu'à la charge commutée, le signal traverse cinq étapes. Chacune a exactement une tâche :

Bouton ─► ESP32-C3 ─► 330 Ω ─► PhotoMOS ─► Shelly 1PM ─► Charge
S1–S3 | compte le | limite | commute | commute et | (pompe,
temps, dessine le courant en isolé | mesure la | moteur
| l'OLED | de la LED | galvanique | charge 230 V | d'aliment.…)

ℹ Pourquoi autant d'étapes ?
L'ESP32 fonctionne avec des 3,3 volts sans danger. Il ne doit jamais « toucher » directement 230 volts. Le PhotoMOS est le pont entre les deux mondes : il sépare complètement la basse tension et la tension secteur par la lumière (détails au chapitre 3). Le Shelly se charge de la commutation proprement dite de la charge et mesure même la puissance au passage.

## 1.3 Ce que la version 3 fait différemment

Ce manuel décrit la version 3 de la carte. Par rapport à la première version, la construction s'est nettement simplifiée :

Le Shelly se trouve à l'extérieur de la carte et se raccorde via une borne (chapitre 13). Cela garde la carte compacte et la tension secteur bien délimitée.
L'ensemble de l'électronique se trouve au dos de la carte. À l'avant ne restent que les trois boutons et le connecteur de l'écran — soit tout ce qui est actionné ou visible.
La carte est à quatre couches avec des plans de masse continus. Cela la rend peu sensible aux perturbations et permet une séparation nette entre tension secteur et basse tension (chapitre 6).
La partie arrière du boîtier est imprimée en 3D (chapitre 5) et suffisamment profonde pour loger la carte et le Shelly.

•

•

•

•

# 2 Sécurité — à lire en premier

Danger de mort par 230 volts
La tension secteur peut être mortelle. Quiconque monte, contrôle et met en service le côté 230 V doit connaître les dangers et maîtriser les règles de l'électrotechnique. En cas de doute : faire appel à un(e) électricien(ne) qualifié(e). Il n'existe ni exception ni urgence qui justifie de s'en passer.

## 2.1 Les règles de base

Tous les premiers tests fonctionnels de l'ESP, des boutons et de l'OLED se déroulent exclusivement via USB — sans aucune tension secteur raccordée.
Le premier test sous 230 V se fait derrière un disjoncteur différentiel (RCD/PRCD, « prise de protection des personnes »), le boîtier fermé. Ne jamais intervenir sur l'appareil ouvert et sous tension.
En amont de l'alimentation doivent figurer un fusible fin (1 A temporisé) et une varistance. Les petits modules AC/DC n'incluent ni l'un ni l'autre.
Sur la carte, il faut respecter entre chaque ligne 230 V et la basse tension une ligne de fuite d'au moins 6 mm. Pourquoi, voir la section 2.2.
Pour le relais PhotoMOS, il faut impérativement utiliser un type avec une tension de blocage ≥ 400 V (chapitre 3). Un optocoupleur ordinaire n'est pas autorisé ici.

•

•

•

•

•

## 2.2 Pourquoi 6 millimètres d'écart

Entre deux surfaces de cuivre sur une carte, le courant ne peut pas seulement sauter à travers l'air, il peut aussi « ramper » le long de la surface — favorisé par la poussière, l'humidité et la saleté. Cette « ligne de fuite » doit être suffisamment grande sous 230 volts. Nous la fixons à 6 mm ; c'est généreux et laisse de la marge. La seule exception autorisée est l'intérieur du relais PhotoMOS lui-même — ce composant est le point de séparation certifié et peut faire cohabiter tension secteur et basse tension sur quelques millimètres (chapitre 6).

⚠ La règle des 6 mm n'est pas une recommandation
Elle est inscrite dans la conception de la carte comme règle de contrôle fixe (chapitres 6 et 8). Quiconque modifie la carte ne doit pas assouplir cette règle — c'est elle qui garantit la sécurité de l'appareil au quotidien.

## 2.3 Le chemin sûr vers la première mise en service

L'ordre choisi dans ce manuel l'est délibérément, afin que vous fassiez tout ce qui est dangereux en dernier et que vous puissiez vous exercer sans risque jusque-là :

Souder les composants et flasher l'ESP sans alimentation secteur, par USB (chapitres 9 et 10).

1

Test USB seul : les boutons, l'OLED et la sortie PhotoMOS sont vérifiés sans aucune tension secteur (chapitre 14).

2

Ce n'est que lorsque tout fonctionne que viennent l'alimentation et le Shelly — et le premier test sous tension se fait derrière un RCD, boîtier fermé (chapitre 14).

3

# 3 Comment fonctionne le système

## 3.1 Les composants et leurs tâches

Composant | Tâche
ESP32-C3 Super Mini | Le « cerveau ». Un petit microcontrôleur avec Wi-Fi. Il lit les boutons, compte le temps, dessine l'OLED, fournit la page web et pilote le PhotoMOS. Alimenté en 5 V, fonctionne en interne en 3,3 V.
Relais PhotoMOS | Le point de séparation galvanique entre 3,3 V et 230 V. Détails à la section 3.3.
Résistance de limitation 330 Ω | Limite le courant à travers la LED interne du PhotoMOS afin qu'elle ne soit pas surchargée.
Alimentation (module AC/DC) | Transforme les 230 V~ en 5 V qui alimentent l'ESP. Un module tout prêt, encapsulé.
Shelly 1PM Mini Gen4 | Commute la charge proprement dite, mesure la puissance et est en plus joignable en Wi-Fi. Se trouve à l'extérieur de la carte.
Écran OLED 0,91" | Affiche l'heure, le compte à rebours et l'état. S'enfiche simplement, sans être soudé.
Fusible + varistance | Protègent contre les surintensités et les surtensions côté secteur.

## 3.2 Pourquoi un Shelly — et pourquoi hors de la carte

Le Shelly 1PM Mini Gen4 est un relais de commutation tout prêt et homologué, avec mesure de puissance. L'utiliser présente trois avantages : la commutation risquée de la charge est confiée à un produit fini certifié ; la puissance est mesurée (on voit si la charge fonctionne réellement) ; et le Shelly est lui-même joignable en Wi-Fi, si l'on souhaite l'intégrer en plus.

Notre carte se contente d'« appuyer » sur l'interrupteur du Shelly — via un vrai signal matériel, sans dépendance au Wi-Fi pour la fonction principale. Dans la version 3, le Shelly se trouve à l'extérieur de la carte et se raccorde via une borne (chapitre 13). Cela garde la carte compacte, les chemins 230 V courts et le montage clair.

ℹ « Switch / Follow »
Le Shelly est réglé de sorte que son relais soit activé exactement aussi longtemps que notre signal est présent (mode Switch ou Follow). Tout le minutage reste ainsi du côté de l'ESP — le Shelly ne fait que suivre.

## 3.3 Ce qu'est un PhotoMOS et pourquoi celui-ci précisément

Un PhotoMOS est un minuscule relais à semi-conducteur. D'un côté se trouve une LED, que l'ESP pilote en 3,3 V. De l'autre, un commutateur piloté par la lumière, autorisé à commuter la tension secteur. Entre les deux, il n'y a que de la lumière — donc une isolation galvanique complète entre basse tension et 230 V.

L'entrée de commutation du Shelly est référencée par rapport à la tension secteur (elle attend un L commuté). C'est pourquoi le PhotoMOS doit supporter une tension de blocage ≥ 400 V — par exemple un Omron G3VM-601BY ou un Panasonic AQY216.

Pas de PC817 & Cie
Un optocoupleur ordinaire (comme le PC817) n'est pas autorisé côté secteur — il ne tient pas la tension de façon sûre et n'est pas conçu pour l'isolation de la tension secteur. N'utiliser qu'un PhotoMOS adapté à la tension secteur, avec ≥ 400 V.

## 3.4 Chaque composant en détail

Voici la fonction exacte de chaque composant — avec les valeurs réellement montées sur la carte v3. Les repères (désignateurs de référence) figurent tels quels sur la sérigraphie d'implantation de la carte.

Repère | Valeur | Fonction précise
U1 | ESP32-C3 Super Mini | Le microcontrôleur Wi-Fi. Fonctionne en 5 V, génère en interne 3,3 V via un régulateur (aussi pour l'OLED). Porte une LED RVB embarquée (WS2812) sur GPIO8. Pilote les boutons, l'OLED, le PhotoMOS et l'interface web.
K1 | G3VM-601AY2 | Le PhotoMOS — l'isolation galvanique entre 3,3 V et 230 V. Broches 1/2 = LED interne (broche 1 via R1 depuis GPIO6, broche 2 à GND), broches 3/4 = commutateur piloté par la lumière (broche 3 = L_F, broche 4 = SW_SHELLY). Tension de blocage ≥ 400 V.
R1 | 330 Ω | Résistance de limitation de la LED de K1. À partir de ~3,3 V moins ~1,2 V de tension directe de la LED, il circule environ 6 mA — suffisant pour une commutation sûre, bien en dessous de la limite de la LED.
PS1 | TSP-05 (5 V / 3 W) | L'alimentation : transforme les 230 V~ (L_F + N) en 5 V/GND pour l'ESP. 3 W = 600 mA — suffisant pour les pics d'émission Wi-Fi (~350 mA) plus l'OLED.
C1 | 220 µF / 10 V | Condensateur de soutien sur +5 V : tamponne les brefs pics de courant lors de l'émission Wi-Fi et évite la chute de tension qui redémarrerait sinon l'ESP.
C2 | 100 nF | Condensateur de découplage directement sur +5 V/GND : absorbe les perturbations haute fréquence près de la puce.
F1 | 1 A temporisé | Fusible fin (5×20 mm) en série : X1 (L_IN) → F1 → L_F. Protège en cas de court-circuit/surintensité. « Temporisé » afin que le courant d'appel de l'alimentation ne le fasse pas fondre à tort.
RV1 | S14K275 (varistance) | Protection contre les surtensions en parallèle entre L_F et N : limite les pics de tension (transitoires de commutation, perturbations réseau) et protège l'alimentation et l'électronique.
J2 | OLED SSD1306 128×32 | L'écran. Adresse I²C 0x3C, 400 kHz. S'enfiche simplement (brochage GND/VCC/SCL/SDA).
SW1–3 | Boutons 6×6 mm | Les trois boutons-poussoirs T1/T2/T3. Un contact à GND, l'autre à GPIO3/4/5 — l'ESP utilise des pull-ups internes, une pression tire la broche à GND.

Et les bornes de raccordement en bord de carte :

Repère | Raccordement | Brochage
X1 | Entrée secteur | 1 = N, 2 = L_IN (230 V entrant)
X2 | Sortie de charge | 1 = O (commuté), 2 = N
X3 | Snubber | 1 = O, 2 = N — pour un circuit RC optionnel avec charges inductives
J1 | Shelly | 1 = SW, 2 = O, 3 = L, 4 = N (vers le Shelly externe, chapitre 13)

# 4 Liste d'achats : matériel et outillage

Tout ce dont vous avez besoin pour un Feeder-Relais. La carte elle-même est confiée à un fabricant (chapitre 7) ; les composants sont commandés et soudés (chapitre 9).

## 4.1 Composants sur la carte

Repère | Composant | Valeur / type | Remarque
U1 | ESP32-C3 Super Mini | 18 × 24 mm, USB-C | Contrôleur Wi-Fi
K1 | Relais PhotoMOS | Omron G3VM-601AY2 (ou -601BY / Panasonic AQY216)

≥ 400 V !

PS1 | Module d'alimentation AC/DC | 5 V / 3 W (classe HLK-PM05) | vérifier l'écartement des broches
— | Écran OLED | 0,91" SSD1306, 128 × 32, I²C | Broches : GND VCC SCL SDA, adresse 0x3C
SW1–3 | Boutons-poussoirs | 6 × 6 mm, course 1,5 mm | position fixe (façade)
R1 | Résistance | 330 Ω | résistance de limitation LED PhotoMOS
F1 | Fusible fin + porte- fusible | 1 A temporisé, 5 × 20 mm | côté primaire, obligatoire
RV1 | Varistance | S14K275 | côté primaire, obligatoire
C1 / C2 | Condensateurs | 220 µF/10 V & 100 nF | soutien 5 V et découplage
X1 | Entrée secteur | 2 broches (L, N) | borne à vis, 230 V entrant
X2 | Sortie de charge | 2 broches (O, N) | vers la charge commutée
X3 | Snubber | 2 broches (O, N) | circuit RC optionnel pour charges inductives
J1 | Raccordement Shelly | 4 broches (SW, O, L, N) | fils courts vers le Shelly externe, chapitre 13
J2 | Connecteur femelle OLED | 1 × 4, pas 2,54 | GND/VCC/SCL/SDA, l'écran s'enfiche

## 4.2 Sous-ensembles hors de la carte

Shelly 1PM Mini Gen4 (type S4SW-001P8EU), max. 8 A / 240 V, dimensions env. 29 × 34 × 16 mm.
Matériel de fixation : ruban adhésif double face VHB ou un clip imprimé en 3D pour fixer le Shelly et l'alimentation dans le boîtier.
Fils courts (p. ex. 0,75 mm²) pour la liaison carte ↔ Shelly et vers la sortie de charge.

## 4.3 Outillage

Fer à souder (à température réglable), étain, tresse à dessouder, flux.
Pince fine, pince coupante, pince à dénuder.
Un câble USB-C de données (attention : beaucoup de câbles bon marché ne servent qu'à charger !) et un PC.
Multimètre (contrôle de continuité et de tension).
Une imprimante 3D pour la partie arrière du boîtier (ou un service d'impression).
Pour le test sous 230 V : un RCD/PRCD.

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
# 5 Le boîtier

Le boîtier se compose de deux parties : la partie avant (la façade d'origine avec sa vitre et les trois poussoirs) et la partie arrière, que vous imprimez vous-même en 3D. La carte se visse par l'arrière sur six colonnettes, l'écran se trouve derrière la vitre.

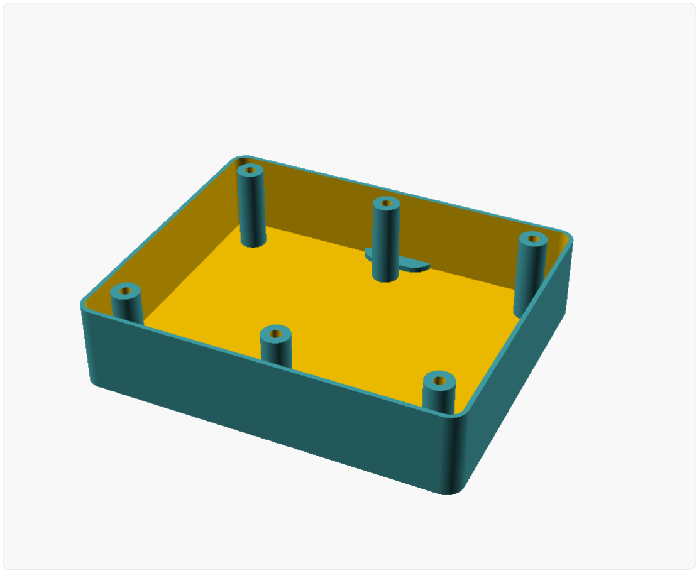
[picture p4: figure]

La partie arrière imprimée en 3D avec ses six colonnettes de vissage et la patte de suspension (en haut).

## 5.1 Composition avant/arrière

La partie avant est le dessus du boîtier d'origine. Elle porte la vitre de protection (derrière laquelle se trouve l'OLED) et les poussoirs qui actionnent, en étant pressés, les trois boutons de la carte. La position des boutons n'est donc pas négociable — ils doivent se trouver exactement sous les poussoirs (chapitre 9).

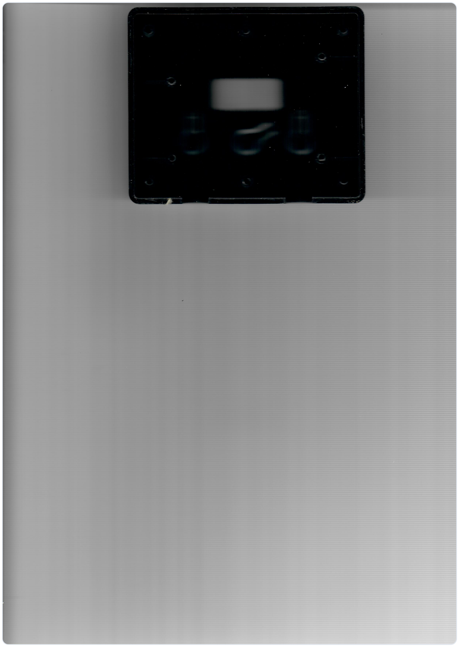
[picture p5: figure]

La partie avant (d'origine) avec sa vitre et ses trois poussoirs.

Dans la version 3, la partie arrière est délibérément plus profonde que l'originale (35 mm au lieu des 5,7 mm d'origine), afin que la carte et le Shelly externe y trouvent confortablement leur place. Une patte de suspension à trou en serrure se trouve en haut, pour la fixation murale.

## 5.2 Imprimer soi-même la partie arrière

Le modèle se trouve dans le projet sous forme de fichier OpenSCAD : box/feeder_back.scad . OpenSCAD est un logiciel gratuit qui génère un modèle 3D à partir d'un fichier texte — l'avantage : toutes les cotes figurent sous forme de variables tout en haut du fichier et peuvent être adaptées.

✓ D'abord imprimer la carte en factice
Le projet contient en plus box/Timer-Ersatzplatine-v3-BOARD.stl — une reproduction 1:1 de la carte (contour, trous de vis, fentes). Imprimez-la à plat et posez-la dans la partie arrière avant de commander la vraie carte. Vous vérifiez ainsi sans risque que tout va bien (chapitre 7).

## 5.3 Budget de hauteur et fixation

La carte se visse par l'arrière avec six vis sur les colonnettes de la partie arrière (pas de colonnettes 45 mm × 70 mm, trou de vis 3,2 mm, fraisage pour la tête de vis côté arrière). Quatre points supplémentaires sur la façade centrent la carte en plus.

Cote | Valeur
Encombrement partie arrière | 109,8 × 90,8 mm
Profondeur partie arrière (v3) | 35 mm
Épaisseur parois et fond | 1,3 mm
Dimensions de la carte | 101,6 × 77,5 mm
Pas des colonnettes | 45 mm (X) × 70 mm (Y)

⚠ Rien ne doit dépasser vers le bas (vers la façade)
Entre la carte et la façade, la place est comptée. Tous les composants hauts se trouvent donc au dos de la carte (chapitre 6). À l'avant ne restent que les boutons plats et le connecteur de l'écran.

1 Ouvrir OpenSCAD et charger box/feeder_back.scad .

Calculer le modèle avec F6 puis, via Fichier → Exporter → STL, l'enregistrer sous forme de fichier imprimable. Un STL déjà prêt est fourni : box/feeder_back_35mm.stl .

2

Charger le STL dans le slicer de votre imprimante. Recommandation : imprimer avec le côté ouvert vers le haut, 3–4 parois, remplissage 20–30 %, aucun support nécessaire.

3

# 6 Comprendre la carte

Vous n'avez pas à concevoir la carte vous-même — elle est fournie prête dans le projet, sous kicad-v3/ . Ce chapitre explique comment elle est construite, afin que vous sachiez, au moment de souder et de contrôler, ce qui va où. Qui souhaite modifier quelque chose lui-même trouvera le guide KiCad au chapitre 8.
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

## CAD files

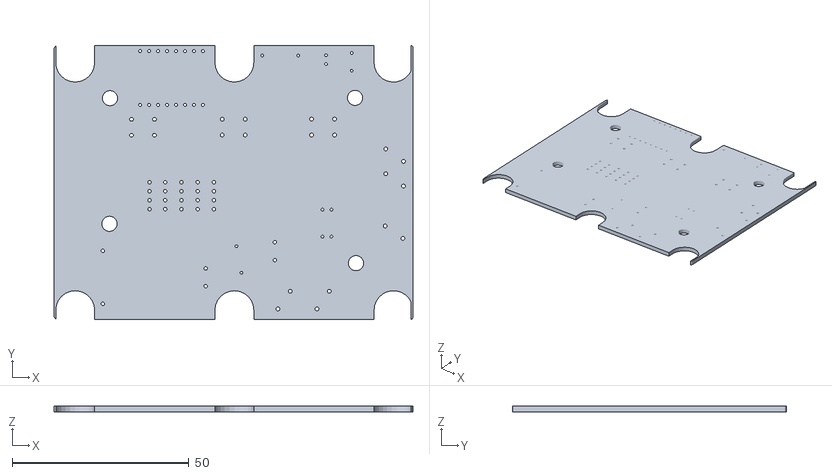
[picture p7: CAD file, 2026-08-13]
box/Timer-Ersatzplatine-v2-BOARD.stl
101.5 x 77.4 x 1.60

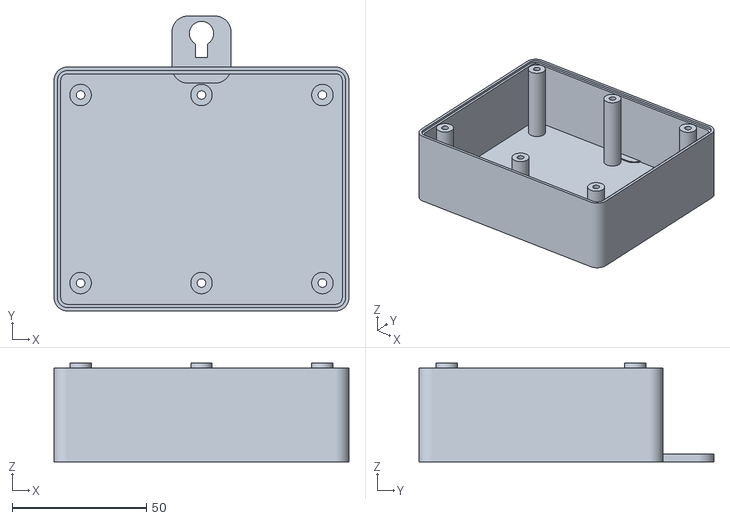
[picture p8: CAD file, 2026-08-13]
box/feeder_back_35mm.stl
109.8 x 109.8 x 36.8

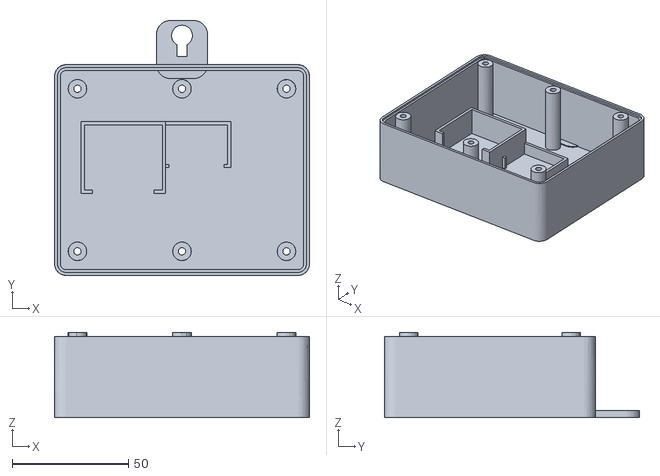
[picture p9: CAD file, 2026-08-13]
box/feeder_back_Shelly_35mm.stl
109.8 x 109.8 x 36.8

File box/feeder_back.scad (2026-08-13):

// ============================================================
//  SuperFish Fish Feeder - Gehaeusehinterteil (tiefere Variante)
//  Parametrisch. Alle Passflaechen wie am Original gemessen;
//  nur die Tiefe (H_OUT) ist geaendert.
//  Datum z=0 = Aussenseite Rueckwand (Wand-Montageflaeche)
//  Rim/Dichtebene (Wandoberkante) = z = H_OUT
//  Einheiten: mm
// ============================================================

/* ---------- Passflaechen (gemessen, NICHT aendern) ---------- */
OUT_W      = 109.8;   // Aussenmass X (Breite)
OUT_Y      = 90.8;    // Aussenmass Y (Hoehe des Korpus, ohne Lasche)
CORNER_R   = 5.0;     // Eckradius aussen
WALL       = 1.3;     // Dichtkante oben (gegen Dichtung im Oberteil) - NICHT aendern
WALL2      = 2.5;     // verstaerkte Aussenwand unterhalb der Dichtzone
SEAL_H     = 1.0;     // Hoehe der Dichtzone unter der Randoberkante (bleibt WALL)
FLOOR      = 2.5;     // Rueckwandstaerke (Boden)

BOSS_OD    = 8.0;     // Dom-Aussendurchmesser
BOSS_ID    = 3.2;     // Schraubloch (Durchgang, Schraube von hinten)
BOSS_PROUD = 1.75;    // Ueberstand Domoberkante ueber Dichtebene (aus E=6.15)
CB_D       = 6.0;     // Senkung (Counterbore) fuer Schraubenkopf hinten - Durchmesser
CB_DEPTH   = 34.5;    // Senkungstiefe: tiefer Zugangskanal, damit kurze Originalschrauben oben greifen

COL_PITCH  = 45.0;    // Domraster X
ROW_PITCH  = 70.0;    // Domraster Y

// Aufhaengelasche (mittig obere Kante)
TAB_W      = 22.0;    // Laschenbreite
TAB_OUT    = 19.0;    // Ueberstand ueber Korpuskante
TAB_T      = 3.0;     // Laschendicke (an Rueckflaeche)
KEY_HEAD_D = 9.0;     // Schluesselloch: grosse Bohrung
KEY_SLOT_W = 4.5;     // Schluesselloch: Schlitzbreite
KEY_SLOT_L = 9.0;     // Schlitzlaenge (Richtung Korpus)

/* ---------- Variabel ---------- */
H_OUT      = 35.0;    // NEUE Gesamttiefe (Original war 5.7)

$fn = 96;
EPS = 0.01;
BOSS_TOP = H_OUT + BOSS_PROUD;

// runde-Rechteck-Prisma (Ecke bei Radius r), Basis bei z0
module rrect_prism(w, d, r, h, z0=0){
    translate([0,0,z0])
    linear_extrude(height=h)
        offset(r=r) offset(r=-r)
            square([w,d], center=false);
}

// Body-Footprint-Zentrum
cx = OUT_W/2;  cy = OUT_Y/2;

// Dompositionen (zentriertes 3x2 Raster)
col = [cx-COL_PITCH, cx, cx+COL_PITCH];
row = [cy-ROW_PITCH/2, cy+ROW_PITCH/2];

module bosses_solid(){
    for(x=col) for(y=row)
        translate([x,y,FLOOR-EPS])
            cylinder(d=BOSS_OD, h=BOSS_TOP-FLOOR+EPS);
}
REAR_COUNTERBORE = true;    // ~6mm tiefe Senkung fuer Schraubenkoepfe (Rueckseite)

module boss_holes(){
    for(x=col) for(y=row){
        // Durchgangsloch komplett durch (Schraubenschaft Ø BOSS_ID)
        translate([x,y,-1]) cylinder(d=BOSS_ID, h=BOSS_TOP+2);
        // zylindrische Senkung fuer den Schraubenkopf, von hinten in den Dom
        if(REAR_COUNTERBORE)
            translate([x,y,-EPS]) cylinder(d=CB_D, h=CB_DEPTH+EPS);
    }
}

module tab(){
    // flache Lasche an +Y-Kante, an der Rueckflaeche (z=0..TAB_T)
    ty0 = OUT_Y - 6;                 // Ueberlappung in den Korpus
    ty1 = OUT_Y + TAB_OUT;
    translate([cx - TAB_W/2, ty0, 0])
        linear_extrude(height=TAB_T)
            offset(r=6) offset(r=-6)
                square([TAB_W, ty1-ty0], center=false);
}
module keyhole(){
    kx = cx;
    ky = OUT_Y + TAB_OUT - KEY_HEAD_D/2 - 2;  // grosse Bohrung nahe Aussenende
    translate([kx, ky, -1]) cylinder(d=KEY_HEAD_D, h=TAB_T+2);
    // Schlitz Richtung Korpus (-Y)
    translate([kx-KEY_SLOT_W/2, ky-KEY_SLOT_L, -1])
        cube([KEY_SLOT_W, KEY_SLOT_L, TAB_T+2]);
}

module feeder_back(){
    difference(){
        union(){
            // Aussen-Tray (Aussenkontur unveraendert; Verstaerkung nach innen)
            difference(){
                rrect_prism(OUT_W, OUT_Y, CORNER_R, H_OUT, 0);
                // untere, verstaerkte Zone: Aussenwand = WALL2
                translate([WALL2, WALL2, 0])
                    rrect_prism(OUT_W-2*WALL2, OUT_Y-2*WALL2,
                                max(CORNER_R-WALL2,0.5),
                                H_OUT-SEAL_H-FLOOR+EPS, FLOOR);
                // obere Dichtzone (letzte SEAL_H unter dem Rand): Wand = WALL
                translate([WALL, WALL, 0])
                    rrect_prism(OUT_W-2*WALL, OUT_Y-2*WALL,
                                max(CORNER_R-WALL,0.5),
                                SEAL_H+1, H_OUT-SEAL_H);
            }
            bosses_solid();
            tab();
        }
        boss_holes();
        keyhole();
    }
}
feeder_back();

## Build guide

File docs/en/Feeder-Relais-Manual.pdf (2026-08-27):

ESP32-C3 · Wi-Fi | 230 V timer | Shelly 1PM Mini Gen4

DIY · Version 3

# Feeder-Relais

## The manual — from the bare board to the finished device in its enclosure

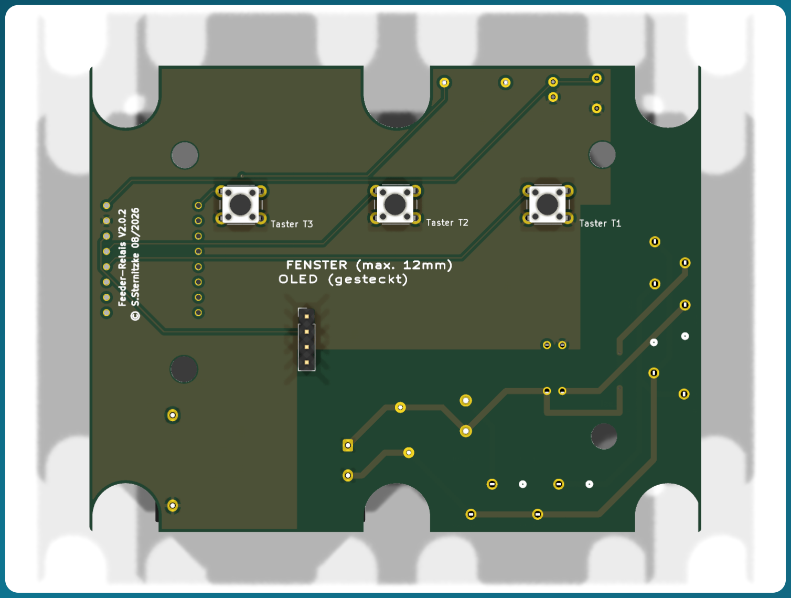
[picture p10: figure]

Edition 1 · August 2026 · English | Hardware v3 · ESPHome firmware · CC BY-NC- SA 4.0

# About This Manual

This manual is written for beginners. You don't need any formal electronics training — just a soldering iron, some patience, and a willingness to type a few commands into a terminal. Every step is described in full: what you do, why you do it, and how you can tell it worked. By the end, you'll be holding a device that switches on a 230 V load (for example, an automatic feeder) at the press of a button for an adjustable time — operable via three buttons, a small display, and a web page on your home network.

This Device Carries 230 Volts
230 volts of mains voltage is life-threatening. Building, testing, and commissioning the power supply must be done by a qualified electrician or a person trained and instructed in electrical safety. In this manual, all tests that are possible without a qualified electrician are carried out exclusively via USB and without any mains voltage. Please read Chapter 2 first.

How to Read This Manual

ℹ Note
Blue boxes provide background knowledge. You can skip them — but they make a lot of things easier to understand.

✓ Tip
Green boxes save you time or nerves.

⚠ Caution
Yellow boxes mark spots where things commonly go wrong.

Stop
Red boxes mark actions that can destroy hardware or injure you. Please always read them.
Terminal commands look like this — they are entered line by line and submitted with | Enter .
Lines starting with | # | are comments and are not typed in:

# This is a comment — for explanation only

esphome run firmware/timer-relais-c3.yaml
© 2026 S. Sternitzke · CC BY-NC-SA 4.0 | ↑ Contents | Feeder-Relais · Manual Edition 1

References such as "Chapter 7" are clickable in the PDF. The "↑ Contents" link at the bottom of every page always takes you back to the overview.

# Contents

### 1 What the Feeder-Relais Is

### 2 Safety — Please Read First

### 3 How the System Works

### 4 Shopping List: Materials and Tools

### 5 The Enclosure

### 6 Understanding the Board

### 7 Getting the Board Manufactured

### 8 KiCad Step by Step (Only for Your Own Changes)

### 9 Assembling the Board

### 10 Flashing the Firmware

### 11 Setting Up Wi-Fi and Operating via the Browser

### 12 Network, Language, and Display

### 13 Connecting the External Shelly

### 14 Assembly and Commissioning

### 15 Firmware Updates and Maintenance

### 16 Troubleshooting

### 17 Appendix: Pinouts, Files, Glossary

# 1 What the Feeder-Relais Is

The Feeder-Relais is a DIY control board that switches on a 230 V load at the press of a button for an adjustable time and then switches itself off again automatically. The name comes from its original use case: it replaces the broken timer board of an automatic feeder. Because at its core it just "presses a switch for a certain time," it is suitable for any load you want to switch on a timer.

## 1.1 What the Device Does

On the front there are three buttons. A short press switches the load on for a stored time:

Button | Label | Default time | Adjustable
S1 | Down / Manual (T1) | 5 seconds | 1–600 s via Wi-Fi
S2 | SET (T2) | 10 seconds | 1–600 s via Wi-Fi
S3 | UP (T3) | 15 seconds | 1–600 s via Wi-Fi

A small OLED display behind the viewing window shows the Wi-Fi signal at the top, the large clock (set via an internet time server), and the Idle status; at the bottom, the date and free memory. While a timer is running, the seconds countdown is shown in the middle and Feed on the right.

Operation is app-free and cloud-free, via a small, mobile-optimized web page that the ESP32 hosts itself (in the browser at http://feeder-relais.local ): trigger timers, adjust times, view network and status values. For connecting to a home automation system (for example ioBroker or Home Assistant), there is also a lightweight JSON interface (Chapter 11).

## 1.2 The Signal Chain

From the button press to the switched load, the signal passes through five stages. Each has exactly one job:

Button ─► ESP32-C3 ─► 330 Ω ─► PhotoMOS ─► Shelly 1PM ─► Load
S1–S3 | counts the | limits | switches | switches and | (pump,
| time, draws | the LED | galvanically | measures the | feed
| the OLED | current | isolated | 230 V load | motor …)

ℹ Why So Many Stages?
The ESP32 operates at a harmless 3,3 volts. It must never "touch" 230 volts directly. The PhotoMOS is the bridge: it completely separates low voltage and mains voltage using light (details in Chapter 3). The Shelly handles the actual switching of the load and even measures the power while doing so.

## 1.3 What Version 3 Does Differently

This manual describes version 3 of the board. Compared to the first version, the design has become considerably simpler:

The Shelly sits outside the board and is connected via a terminal block (Chapter 13). This keeps the board small and the mains wiring easy to follow.
All the electronics are on the back of the board. Only the three buttons and the display connector remain on the front — that is, everything that is operated or seen through the front panel.
The board is four layers with continuous ground planes. This keeps it low-noise and allows a clean separation between mains voltage and low voltage (Chapter 6).
The enclosure back piece is 3D-printed (Chapter 5) and is deep enough to hold both the board and the Shelly.

•

•

•

•

# 2 Safety — Please Read First

Danger to Life from 230 Volts
Mains voltage can be fatal. Anyone who builds, tests, and commissions the 230 V side must know the hazards and master the rules of electrical engineering. When in doubt: bring in a qualified electrician. There is no exception and no hurry that justifies skipping this.

## 2.1 The Basic Rules

All initial function tests of the ESP, buttons, and OLED are carried out exclusively via USB — with no mains voltage whatsoever connected.
The first 230 V test takes place behind a residual-current device (RCD/PRCD, a "personal protection plug"), with the enclosure closed. Never work inside the open device while it is live.
A fine fuse (1 A slow-blow) and a varistor belong upstream of the power supply. The small AC/DC modules do not include either of these themselves.
On the board, a minimum of 6 mm distance (creepage distance) applies between every 230 V line and the low-voltage side. Why, is explained in Section 2.2.
For the PhotoMOS relay, a type with ≥ 400 V blocking voltage must be used (Chapter 3). An ordinary optocoupler is not permitted here.

•

•

•

•

•

## 2.2 Why 6 Millimeters of Clearance

Between two copper areas on a board, current can not only jump through the air but also creep along the surface — aided by dust, moisture, and dirt. At 230 volts, this "creepage distance" must be large enough. We fix it at 6 mm, which is generous and leaves margin. The only permitted exception is the inside of the PhotoMOS relay itself — this component is the certified isolation barrier and is allowed to carry mains and low voltage within a few millimeters of each other (Chapter 6).

⚠ The 6 mm Rule Is Not a Recommendation
It is encoded in the board design as a fixed design rule (Chapters 6 and 8). Anyone modifying the board must not weaken this rule — it is the reason the device stays safe in everyday use.

## 2.3 The Safe Path to First Commissioning

The order in this manual is deliberately chosen so that you do anything dangerous last and can practice safely until then:

Assemble the board and flash the ESP without a power supply via USB (Chapters 9 and 10).

1

USB-only test: the buttons, OLED, and the PhotoMOS output are tested completely without mains voltage (Chapter 14).

2

Only once everything works do the power supply and Shelly get added — and the first mains test runs behind an RCD with the enclosure closed (Chapter 14).

3

# 3 How the System Works

## 3.1 The Components and Their Jobs

Component | Job
ESP32-C3 Super Mini | The "brain." A small microcontroller with Wi-Fi. It reads the buttons, counts the time, draws the OLED, hosts the web page, and drives the PhotoMOS. Supplied with 5 V, operates internally at 3,3 V.
PhotoMOS relay | The galvanic isolation barrier between 3,3 V and 230 V. Details in Section 3.3.
Series resistor 330 Ω | Limits the current through the PhotoMOS's internal LED so it isn't overloaded.

Power supply
(AC/DC module)

Turns 230 V~ into the 5 V that runs the ESP. A ready-made, encapsulated module.

Shelly 1PM Mini
Gen4

Switches the actual load, measures the power, and is additionally reachable over Wi-Fi. Sits outside the board.

OLED display
0,91"

Shows the clock, countdown, and status. Only plugged on, not soldered.

Fuse + varistor Protect against overcurrent and overvoltage on the mains side.

## 3.2 Why a Shelly — and Why Outside the Board

The Shelly 1PM Mini Gen4 is a ready-made, tested switching relay with power measurement. Using it has three advantages: the risky task of switching the load is handled by a certified, off-the-shelf product; the power is measured (so you can see whether the load is actually running); and the Shelly is itself reachable over Wi-Fi, in case you want to integrate it separately as well.

Our board only "presses the switch" for the Shelly — as a genuine hardware signal, with no Wi-Fi dependency for the core function. In version 3, the Shelly sits outside the board and is connected via a terminal block (Chapter 13). This keeps the board small, the 230 V paths short, and the layout easy to follow.

ℹ "Switch / Follow"
The Shelly is configured so that its relay is on for exactly as long as our signal is present (operating mode Switch or Follow). This keeps all the timing with the ESP — the Shelly only follows.

## 3.3 What a PhotoMOS Is, and Why This One Specifically

A PhotoMOS is a tiny semiconductor relay. On one side sits an LED, which the ESP drives with 3,3 V. On the other side is a light-controlled switch that is allowed to switch mains voltage. Between them lies only light — that is, a complete galvanic isolation between low voltage and 230 V.

The Shelly's switch input is referenced to mains voltage (it expects a switched L). That's why the PhotoMOS must withstand ≥ 400 V blocking voltage — for example an Omron G3VM-601BY or a Panasonic AQY216.

No PC817 & Co.
An ordinary optocoupler (such as a PC817) is not permitted for the mains side — it does not hold the voltage safely and is not built to isolate mains voltage. Only use a PhotoMOS rated for mains voltage with ≥ 400 V.

## 3.4 Every Component in Detail

Here is the exact function of each component — with the values actually fitted on the v3 board. The reference designators appear this way on the board's silkscreen.

Reference | Value | Exact function
U1 | ESP32-C3 Super Mini | The microcontroller with Wi-Fi. Runs on 5 V, generates 3,3 V internally via a regulator (also for the OLED). Carries an onboard RGB LED (WS2812) on GPIO8. Drives the buttons, OLED, PhotoMOS, and the web interface.
K1 | G3VM-601AY2 | The PhotoMOS — the galvanic isolation between 3,3 V and 230 V. Pins 1/2 = internal LED (pin 1 via R1 from GPIO6, pin 2 to GND), pins 3/4 = light-controlled switch (pin 3 = L_F, pin 4 = SW_SHELLY). Blocking voltage ≥ 400 V.
R1 | 330 Ω | Series resistor for the K1 LED. From ~3,3 V minus ~1,2 V LED forward voltage, about 6 mA flows — enough for reliable switching, well below the LED's limit.
PS1 | TSP-05 (5 V / 3 W) | The power supply: turns 230 V~ (L_F + N) into 5 V/GND for the ESP. 3 W = 600 mA — enough for the Wi-Fi transmit peaks (~350 mA) plus the OLED.
C1 | 220 µF / 10 V | Bulk capacitor on +5 V: buffers short current spikes during Wi-Fi transmission and prevents the voltage dip that would otherwise restart the ESP.
C2 | 100 nF | Decoupling capacitor directly on +5 V/GND: absorbs high-frequency noise close to the chip.
F1 | 1 A slow-blow | Fine fuse (5×20 mm) in series: X1 (L_IN) → F1 → L_F. Protects against short circuit/overcurrent. "Slow-blow" so the power supply's inrush current doesn't trip it falsely.
RV1 | S14K275 (varistor) | Overvoltage protection in parallel between L_F and N: limits voltage spikes (switching transients, mains disturbances) and protects the power supply and electronics.
J2 | OLED SSD1306 128×32 | The display. I²C address 0x3C, 400 kHz. Only plugged on (pinout GND/VCC/SCL/SDA).
SW1–3 | Push button 6×6 mm | The three tactile switches T1/T2/T3. One terminal to GND, the other to GPIO3/4/5 — the ESP uses internal pull-ups, and a press pulls the pin to GND.

And the terminal blocks at the edge of the board:

Reference | Connection | Pinout

X1 | Mains input | 1 = N, 2 = L_IN (230 V in)
X2 | Load output | 1 = O (switched), 2 = N
X3 | Snubber | 1 = O, 2 = N — for an optional RC network with inductive loads
J1 | Shelly | 1 = SW, 2 = O, 3 = L, 4 = N (to the external Shelly, Chapter 13)

# 4 Shopping List: Materials and Tools

Everything you need for one Feeder-Relais. You have the board itself manufactured (Chapter 7); the components are ordered and soldered on (Chapter 9).

## 4.1 Components on the Board

Reference | Component | Value / Type | Note
U1 | ESP32-C3 Super Mini | 18 × 24 mm, USB-C | Controller with Wi-Fi
K1 | PhotoMOS relay | Omron G3VM-601AY2 (or -601BY / Panasonic AQY216)

≥ 400 V!

PS1 | AC/DC power supply
module
5 V / 3 W (HLK-PM05 class) | Measure pin spacing first
— | OLED display | 0,91" SSD1306, 128 × 32, I²C | Pins: GND VCC SCL SDA, address 0x3C
SW1–3 | Tactile switch | 6 × 6 mm, travel 1,5 mm | Position is fixed (front panel)
R1 | Resistor | 330 Ω | PhotoMOS LED series resistor
F1 | Fine fuse + holder | 1 A slow-blow, 5 × 20 mm | primary side, mandatory
RV1 | Varistor | S14K275 | primary side, mandatory
C1 / C2 | Capacitors | 220 µF/10 V & 100 nF | 5 V buffer and decoupling
X1 | Mains input | 2-pin (L, N) | Screw terminal, 230 V in
X2 | Load output | 2-pin (O, N) | to the switched load
X3 | Snubber | 2-pin (O, N) | optional RC network for inductive loads
J1 | Shelly connector | 4-pin (SW, O, L, N) | short wires to the external Shelly, Chapter 13
J2 | OLED header socket | 1 × 4, 2,54 mm pitch | GND/VCC/SCL/SDA, display is plugged on

## 4.2 Assemblies Outside the Board

Shelly 1PM Mini Gen4 (type S4SW-001P8EU), max. 8 A / 240 V, dimensions approx. 29 × 34 × 16 mm.
Mounting material: double-sided VHB tape or a 3D-printed clip to secure the Shelly and power supply inside the enclosure.
Short wires (e.g. 0,75 mm²) for connecting the board to the Shelly and to the load output.

## 4.3 Tools

Soldering iron (temperature-controlled), solder, desoldering braid, flux.
Fine tweezers, side cutters, wire strippers.
A USB-C data cable (careful: many cheap cables can only charge!) and a PC. Multimeter (continuity and voltage testing).
A 3D printer for the enclosure back piece (or a print service).
For the 230 V test: an RCD/PRCD.

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
# 5 The Enclosure

The enclosure consists of two parts: the front piece (the original front panel with the viewing window and the three button plungers) and the back piece, which you 3D print yourself. The board is screwed to six bosses from behind, and the display sits behind the viewing window.


The 3D-printed back piece with the six screw bosses and the mounting tab (top).

## 5.1 Structure: Front and Back Piece

The front piece is the original enclosure's top part. It carries the viewing window (behind which sits the OLED) and the plungers that, when pressed, actuate the three buttons on the board. This is why the position of the buttons is non-negotiable — they must sit exactly under the plungers (Chapter 9).


The front piece (original) with the viewing window and the three button plungers.

In version 3, the back piece is deliberately deeper than the original (35 mm instead of the original 5,7 mm), so that the board and the external Shelly fit comfortably inside. A mounting tab with a keyhole slot sits at the top edge for wall mounting.

## 5.2 Printing the Back Piece Yourself

The template is available as an OpenSCAD file in the project under box/feeder_back.scad . OpenSCAD is a free program that generates a 3D model from a text file — the advantage: all dimensions appear as variables at the very top of the file and can be adjusted.

✓ Print the Board Mock-Up First
The project also includes box/Timer-Ersatzplatine-v3-BOARD.stl — a 1:1 replica of the board (outline, screw holes, slots). Print it flat and place it into the back piece before you order the real board. This lets you check the fit safely (Chapter 7).

## 5.3 Height Budget and Mounting

The board is screwed from behind onto the back piece's bosses with six screws (boss grid 45 mm × 70 mm, screw hole 3,2 mm, countersunk for the screw head on the back). Four additional points on the front panel further center the board.

Dimension | Value
Back piece outer size | 109,8 × 90,8 mm
Back piece depth (v3) | 35 mm
Wall and floor thickness | 1,3 mm
Board size | 101,6 × 77,5 mm
Boss grid | 45 mm (X) × 70 mm (Y)

⚠ Nothing May Protrude Downward (Toward the Front)
Space between the board and the front panel is tight. That's why all tall components sit on the back of the board (Chapter 6). Only the flat buttons and the display connector remain on the front.

1 Open OpenSCAD and load box/feeder_back.scad .

Press F6 to render the model and save it as a printable file via File → Export → STL. A ready-made STL is already included: box/feeder_back_35mm.stl .

2

Load the STL into your printer's slicer. Recommendation: print with the open side facing up, 3–4 wall lines, 20–30 % infill, no supports needed.

3

# 6 Understanding the Board

You don't have to design the board yourself — it is finished and ready in the project under kicad-v3/ . This chapter explains how it is laid out, so that during assembly and testing you know what belongs where. Anyone who wants to change something themselves will find the KiCad guide in Chapter 8.

## 6.1 Front and Back

In version 3, all the electronics sit on the back of the board. Only the three buttons and the OLED socket remain on the front (toward the front panel) — everything that is operated or seen.

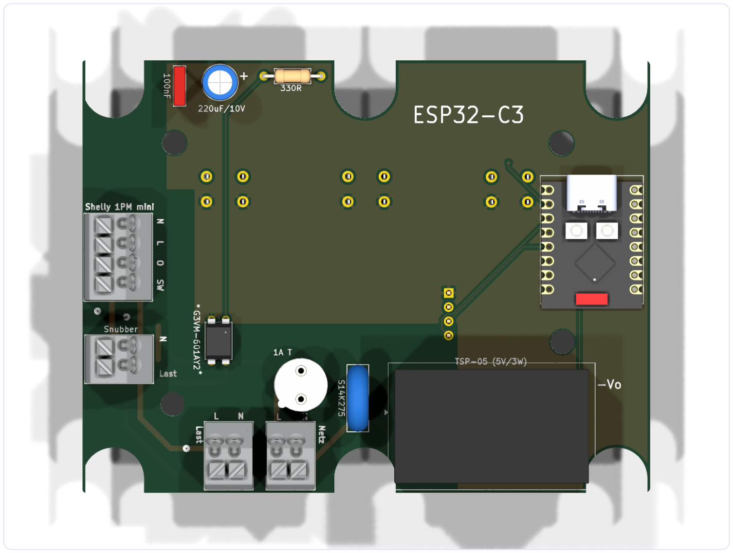
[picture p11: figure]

The back carries the ESP, power supply, PhotoMOS, and the 230 V terminal blocks. Mains voltage (bottom) and low voltage (top) are clearly separated spatially.

## 6.2 Four Layers and the Ground Planes

The board has four copper layers: the two outer layers (front and back) carry the traces, and the two inner layers are continuous ground planes in the low-voltage area. Such ground planes act as a calm reference plane: they keep the design low-noise and the Wi-Fi function stable.

ℹ Important for Safety
In the mains-voltage area there is no inner copper. The 230 V lines run exclusively on the two outer layers, and the ground planes maintain at least 6 mm of clearance from mains voltage everywhere. This ensures that no dangerous proximity can occur anywhere inside the board.

## 6.3 Mains Voltage Only on the Outside: the 6-Millimeter Rule

The five nets L_IN , L_F , N , SW_SHELLY , and O_LAST carry 230 volts. They are grouped into their own net class "230V" (wider traces, larger clearances) and all sit in the bottom left, well away from the electronics. A design rule encoded in the design requires 6 mm of clearance between every 230 V net and every low-voltage net.

The only exception is the PhotoMOS relay K1: its package is the certified isolation barrier (pins 1/2 = low voltage, pins 3/4 = mains voltage). Only there are the two worlds allowed to meet within a few millimeters — that is exactly what the component is built for.

## 6.4 The Nets and the Pinout

The following overview shows what each line carries:

Net name | Carries | Connects
L_IN | 230 V (unfused) | Mains input X1 → fuse F1
L_F | 230 V (fused) | F1 → varistor RV1, power supply PS1, PhotoMOS K1.3, Shelly J1.L
N | 230 V neutral | X1 → RV1, PS1, Shelly J1.N, load X2, snubber X3
SW_SHELLY | 230 V switched | PhotoMOS K1.4 → Shelly J1.SW
O_LAST | 230 V switched | Shelly J1.O → load output X2 + snubber X3
+5V | Low voltage | Power supply → ESP 5V, C1, C2
GND | Low voltage | Ground: ESP, buttons, PhotoMOS, OLED
+3V3 | Low voltage | ESP 3V3 output → OLED

The ESP32-C3 uses these pins:

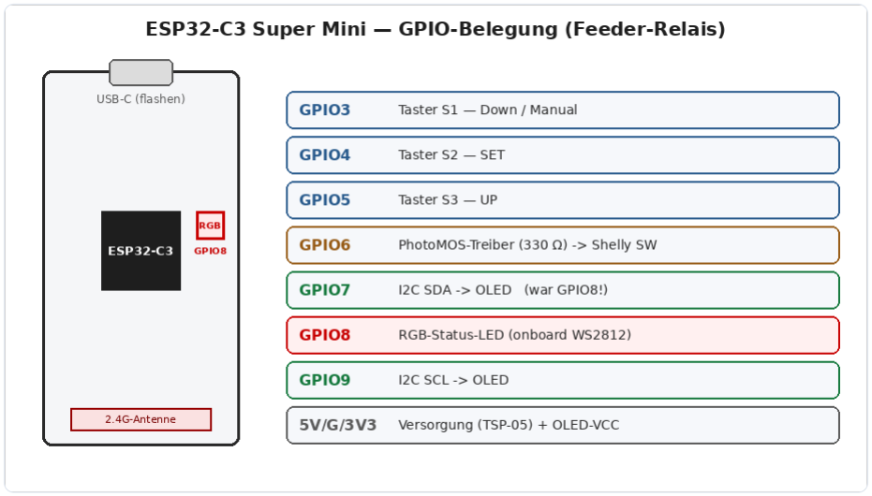
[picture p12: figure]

The pins used on the ESP32-C3 Super Mini.

Pin | Function
5V / G | Supply from the power supply
3V3 | Supplies the OLED

GPIO3 / 4 / 5 | Buttons T1 / T2 / T3
GPIO6 | PhotoMOS driver (via 330 Ω)
GPIO7 | I²C SDA (OLED)
GPIO8 | Onboard RGB LED (status)
GPIO9 | I²C SCL (OLED)

ℹ Why SDA on GPIO7 Instead of GPIO8?
The ESP module's small RGB status LED sits on GPIO8. If I²C were there instead, the data traffic would drive the LED in an uncontrolled way. That's why SDA is on GPIO7. The same RGB LED later shows the device's status traffic light (Chapter 11).

## 6.5 Every ESP Connection in Exact Detail

This table is the binding alignment between board and firmware. On the left is what the firmware ( timer-relais-c3.yaml ) does with the pin — with its exact configuration; on the right, where the board routes it. Both sides must match exactly, or the device will not work.

ESP pin | Firmware (ID & configuration) | Board | Function in detail
| pull-up, inverted, 30 ms | | Button S1 (Down/Manual). Idle level HIGH; a press pulls it to GND (LOW) → counts as "pressed." Short press = trigger timer 1.
GPIO3 | btn_s1 | · input, internal

debounce

Pad 3 → | /BTN1 | →
button S1 to GND
GPIO4 | btn_s2 | · input, pull-up,
inverted, 30 ms
Pad 4 → | /BTN2 | →
button S2 to GND

Button S2 (SET). Short = timer 2; long ≥ 3 s = info menu.

GPIO5 | btn_s3 | · input, pull-up,
inverted, 30 ms
Pad 5 → | /BTN3 | →
button S3 to GND

Button S3 (UP). Short = timer 3; long ≥ 1,2 s = stop everything.

GPIO6 | shelly_trigger | · GPIO
output
Pad 6 → | /
PMOS_DRV | →
R1 330 Ω → K1
LED anode

Drives the PhotoMOS. HIGH = LED on = PhotoMOS conducts = Shelly SW gets L → load on. LOW = off.

GPIO7 | i2c: sda | · 400 kHz | Pad 7 → | /SDA | →
OLED J2.4

I²C data line to the OLED. Deliberately on GPIO7 (not GPIO8).

GPIO8 | status_led | · WS2812
(GRB), dimmed

on-module —
no net on the
board (Pad 8
| | | unused)

Onboard RGB status LED (traffic light green/yellow/red). It sits fixed on GPIO8 of the module; that's why no second signal may be placed here — the reason SDA moved to GPIO7.

GPIO9 | i2c: scl | · 400 kHz | Pad 9 → | /SCL | →
OLED J2.3

I²C clock line to the OLED (address 0x3C).

5V /
GND
Module supply | /+5V | / | GND | from
the power supply

5 V from the AC/DC module; GND is the common ground (also the inner layers).

3V3 Output of the onboard
regulator
/+3V3 | → OLED-
| VCC

The ESP generates 3,3 V internally and uses it to power the OLED.

⚠ This Exact Alignment Is Critical
If SDA is accidentally routed to GPIO8 on the board (where the WS2812 sits), the OLED stays black and the LED signal interferes with the data line. When building your own, therefore check: OLED SDA must be connected to ESP pad 7 (GPIO7), SCL to pad 9 (GPIO9) — GPIO8 stays unused.

# 7 Getting the Board Manufactured

You don't build a four-layer board at home — you have it manufactured by a PCB fabricator. Today that's cheap and easy: you upload a handful of files and receive the finished boards by mail.

## 7.1 First, a Test in Plastic

✓ The Fit-Check Trick Saves Money
Before ordering boards, print the included box/Timer-Ersatzplatine-v3-BOARD.stl 1:1 on your 3D printer (flat, no supports) and place it into the printed back piece. Does the outline fit? Do the six slots line up with the bosses? Do the screw holes sit right? These five minutes save you an expensive misorder.

Alternatively (or in addition), print the board outline on paper at 1:1 scale and cut it out.

## 7.2 Generating Gerber Data

"Gerber" is the standard file format that manufacturers expect boards in — one file per layer, plus the drill data. The finished Gerber files are already included in the project; you can generate them from KiCad like this:

1 Open the project kicad-v3/Timer-Ersatzplatine-v3.kicad_pcb in KiCad.

2 File → Fabrication Outputs → Gerbers — select all standard layers, export.

3 In the same dialog, generate the drill files (Excellon).

4 Pack all generated files into a ZIP archive.

## 7.3 Ordering from a Manufacturer

Upload the ZIP to a provider such as JLCPCB, PCBWay, or Aisler. Important settings:

Setting | Value
Layers | 4
Board thickness | 1,6 mm (standard)
Surface finish | Lead-free HASL or ENIG
Copper | 1 oz (35 µm)
Color | doesn't matter

⚠ Set It to Four Layers
Really choose 4 layers. A two-layer build would have no inner ground planes — Wi-Fi performance and noise immunity would be worse, and the design's rule checks would no longer fit.

# 8 KiCad Step by Step (Only for Your Own Changes)

You only need this chapter if you want to modify the board yourself. If you're just building the existing design, you can skip it — the finished manufacturing data is included. KiCad is a free program for board design (tested with KiCad 8/9/10; menu names may vary slightly).

## 8.1 Opening the Project and Checking the Schematic

## 8.2 Footprints and Net Classes

Each component symbol is linked to a footprint — the solder pattern on the board. Under Tools → Assign Footprints, check that, for example, PS1 matches the power supply you actually bought (measure the pin spacing!) and that the PhotoMOS matches the SMD or DIP package.

The net classes are defined in the project file and must not be changed: Default (0,2 mm clearance and trace width) and 230V (1,0 mm clearance and trace width) with the five nets L_IN, L_F, N, SW_SHELLY, O_LAST.

1 Start KiCad and open kicad-v3/Timer-Ersatzplatine-v3.kicad_pro .

2 Start the schematic editor. It shows how all the components are connected.

Run Inspect → Electrical Rules Checker (ERC). Warnings about "unconnected power pins" are known and non-critical.

3

## 8.3 The 6-Millimeter Rule and the DRC

The creepage-distance rule exists as its own file | Timer-Ersatzplatine-v3.kicad_dru | in the
project. It requires 6 mm between 230 V and low voltage — with the deliberate exception of the PhotoMOS K1:

(version 1)
(rule "230V->SELV 6mm (K1-Barriere ausgenommen)" (condition "... 230-V-Netz gegen Nicht-230-V-Netz, K1 ausgenommen ...")
(constraint creepage (min 6mm))
(constraint clearance (min 6mm)))

After every change, run the DRC (Design Rules Check, Inspect → Design Rules Checker) until it comes back clean.

⚠ Pull Ground Planes Back 6 mm
The automatic ground-plane fill only honors the net-class clearance, not the 6 mm rule. That's why the ground planes are geometrically shaped to stay 6 mm away from mains voltage everywhere. Anyone who redraws the planes must maintain this distance by hand.

## 8.4 Manufacturing Data

Once the DRC and visual inspection (3D view with Alt+3 ) are clean, export the Gerber and drill data as described in Chapter 7.

# 9 Assembling the Board

"Assembling" means soldering the components onto the board. We go from the flat parts to the tall ones — this way the board always lies stably while you solder.

## 9.1 Order and Tools

Recommended order: R1 → C2 → PhotoMOS → buttons → OLED socket J4 → C1 → fuse holder F1 → varistor RV1 → terminal blocks. The ESP goes on only once it has been flashed and tested (Chapters 10 and 14).

## 9.2 The SMD Components

Depending on the type, the PhotoMOS is a small SMD component. Here's how to solder it cleanly:

ℹ PhotoMOS Orientation
Pin 1 is marked (dot or chamfered corner). The low-voltage side (pins 1/2) faces the electronics, the mains-voltage side (pins 3/4) faces the 230 V corner. The solder pattern dictates the direction — don't guess, go by the silkscreen marking.

1 Tin one pad thinly.

Place the component with tweezers and solder it to the tinned pad — check its orientation.

2

3 Solder the remaining pins. Flux helps; use a small amount of solder to avoid bridges.

## 9.3 The Through-Hole Components and Connectors

Buttons SW1–3: place them exactly — they must later sit precisely under the front panel's plungers. Press flush onto the board, then solder.
OLED socket J4: solder the header socket (1×4) so it stands vertically. The OLED is later only plugged on, not soldered.
Fuse, varistor, terminal blocks: in the 230 V corner, with clearance from the electronics. Solder them properly, with no cold joints.

ℹ The OLED Is Plugged, Not Soldered
You solder a pin header (facing backward) onto the OLED that fits into socket J4. The display then sits right against the viewing window with a thin foam pad. This keeps it replaceable and the build height low.

•

•

•

# 10 Flashing the Firmware

The "firmware" is the program that runs on the ESP. The very first time, it goes onto the chip via a USB cable. All later updates then happen wirelessly (Chapter 15).

## 10.1 What You Need

the ESP32-C3 Super Mini (not yet soldered in),
a USB-C data cable — many cheap cables can only charge; with those the chip is not recognized,
a PC with Google Chrome or Microsoft Edge (Path B) — or ESPHome installed on the PC (Path A).

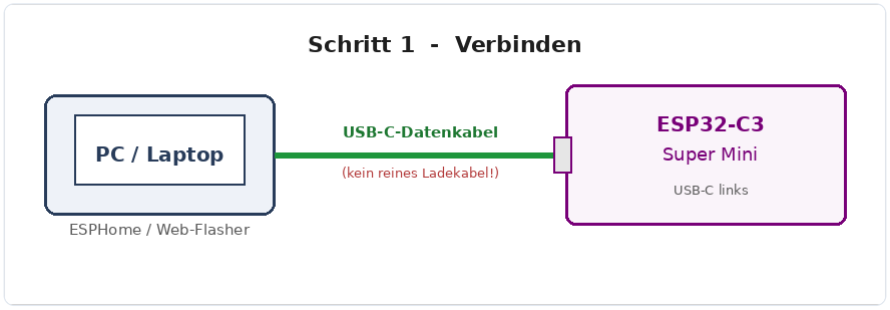
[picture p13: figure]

Connecting the ESP32-C3 to the PC via USB-C.

ℹ You Don't Have to Compile Anything
Ready-made images are included in the project under | firmware/build/ : | feeder-
relais.factory.bin | for the initial flash and | feeder-relais.ota.bin | for later web
updates. They contain no Wi-Fi credentials — you set those up after flashing (Chapter 11).

•
•

•

## 10.2 Path A — Using ESPHome

ESPHome is the tool used to build and flash the firmware. A | secrets.yaml | is not needed — no
Wi-Fi data is compiled in.

✓ Linux: "Permission Denied"?
If access to | /dev/ttyACM0 | is denied, add your user to the | dialout | group and log in
again:

sudo usermod -aG dialout $USER

1 Plug in the ESP via USB-C.

Run in the project folder:

esphome run firmware/timer-relais-c3.yaml

2

ESPHome compiles, asks for the serial port (on Linux, e.g. /dev/ttyACM0 ; on Windows, a COMx ), and flashes.

3

4 After the restart, the ESP opens its setup hotspot → continue with Chapter 11.

## 10.3 Path B — In the Browser

For the ready-made feeder-relais.factory.bin , with no installation at all:

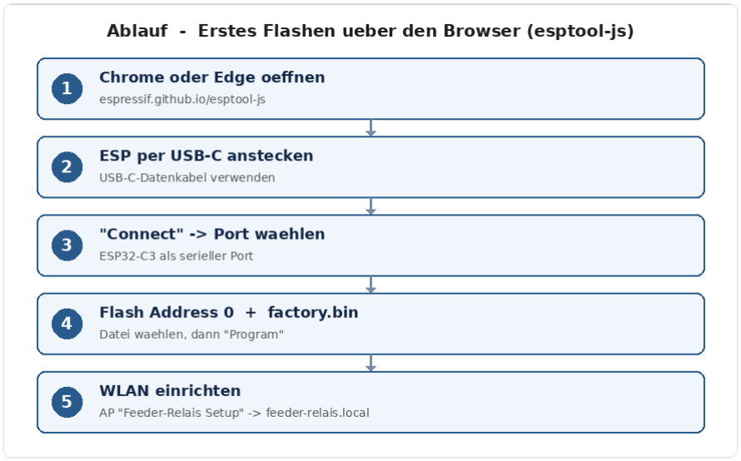
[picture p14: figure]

The flashing flow in the browser via the web flasher.

1 | Open | https://espressif.github.io/esptool-js/ | in Chrome/Edge.

2 Plug in the ESP via a USB-C data cable.

3 | Leave the baud rate at | 115200 , click Connect, and select the ESP's serial port.
Under Flash Address, enter | 0 , use Choose File to select | feeder-relais.factory.bin ,
then Program. Wait until "Hard resetting…" appears.

4

5 Continue with Chapter 11.

## 10.4 If Flashing Gets Stuck

Symptom | Cause / Fix
ESP isn't recognized at all | Charge-only cable instead of a data cable → try another USB-C cable, another port
No port in the browser | Use Chrome/Edge; on Windows, install drivers if needed (CH340/CP210x)
"Connect" fails | Boot mode: hold BOOT + tap RESET + release BOOT, then connect again
No | ….local | afterward | set up Wi-Fi first (Chapter 11); mDNS needs a moment

# 11 Setting Up Wi-Fi and Operating via the Browser

## 11.1 The Setup Hotspot

The firmware deliberately ships with no Wi-Fi credentials. After flashing, the ESP opens its own hotspot:

ℹ Set It Up Once, Never Again
The Wi-Fi credentials are stored under a fixed storage key and survive firmware updates. For a factory reset, flash the factory image with "Erase all flash."

On your phone/PC, connect to the Wi-Fi network "Feeder-Relais Setup" (password feeder1234 ).

1

2 | A login window opens (otherwise go to | http://192.168.4.1 ).

3 Select your home Wi-Fi, enter the password, save — the ESP restarts and connects.

4 | From now on it's reachable at | http://feeder-relais.local .

## 11.2 The Web Interface

http://feeder-relais.local opens a mobile web app with five tabs:

Home: three large buttons (trigger T1/T2/T3), a live countdown, and Stop.
Times: the language selector (German/English/French) at the top, below it the three timer durations (1–600 s), stored permanently.
Network: Wi-Fi, IP mode DHCP/static, NTP server, hostname, Wi-Fi roaming, restart (Chapter 12).
Status: version, uptime, free memory, Wi-Fi with signal bars, IP/MAC, reset reason, relay state.
Service: live log, firmware update, and restart (Chapter 15).

## 11.3 The Status Traffic Light and the JSON Interface

The header shows a status dot: green = everything OK, yellow = a timer is running, red = a fault while idle (e.g. OLED unreachable or no Wi-Fi). The same traffic light is shown on the device by the dimmed onboard RGB LED.

For home automation, the ESP offers a JSON interface. The most important endpoints:

Call | Effect
GET /api/status | all values as JSON (active, time remaining, relay, times, Wi-Fi …)
POST /api/trigger?button=N | trigger button N (1–3) with its time
POST /api/trigger?seconds=N | switch on ad hoc for N seconds
POST /api/trigger? seconds=N&src=adapter | as above, tags the source — appears as trg (button/api/ adapter) in the status and log
POST /api/stop | switch off immediately
POST /api/config? time1=A&time2=B&time3=C | set the times (each 1–600 s)

ℹ ioBroker Example
Set button 1's time to 8 seconds: POST http://feeder-relais.local/api/config?time1=8 .

•
•

•

•

•

# 12 Network, Language, and Display

## 12.1 Network Settings

In the Network tab you can set:

IP mode: DHCP (default) or static (with IP/gateway/mask/DNS). The static IP is applied on the next connection and is active after a restart.
NTP server: the time server used to set the clock (default de.pool.ntp.org ).
Hostname: the name on the network (default feeder-relais ). It is changed at runtime — the ….local address takes effect immediately.

## 12.2 Wi-Fi Roaming

The Wi-Fi roaming (802.11k/v) switch only makes sense if you have multiple access points with the same SSID (mesh/UniFi) that support the technology. In that case, the device can actively switch to the stronger access point. Default: off. After toggling it, the "Reconnect now" button helps it take effect immediately.

## 12.3 Operating the Buttons and OLED

On the device, the buttons are labeled: S1 = Down/Manual, S2 = SET, S3 = UP.

short press S1 / S2 / S3 → triggers timer 1 / 2 / 3 with its configured time.
long press UP (S3) ≥ 1,2 s → stops all timers, switches off.
long press SET (S2) ≥ 3 s → opens an info menu (view-only: Wi-Fi, IP, time, system). S1/ S3 scroll, short SET closes it.

The OLED (128 × 32) shows the Wi-Fi bar at the top, the large clock or countdown, and the status (Idle/Feed); at the bottom, the date and free memory. Weekday, status, and menu titles follow the configured language. Until the first time synchronization, it shows "--:--".

•

•
•

•
•
•

# 13 Connecting the External Shelly

Wire It Up Only With the Power Off
The Shelly carries 230 volts. All wiring work is done de-energized, with the mains plug pulled or the circuit breaker switched off — and, when in doubt, by a qualified electrician.

## 13.1 Wiring

The Shelly has four terminals: L, N, SW (switch input), and O (load output). Four short wires connect it to the board's terminal block J1:

Board (J1) | → Shelly | Meaning
J1.3 (L_F) | L | Phase (fused)
J1.4 (N) | N | Neutral
J1.1 (SW_SHELLY) | SW | our switched signal (from the PhotoMOS)
J1.2 (O_LAST) | O | switched load to the output

The Shelly is secured lying flat inside the enclosure (VHB tape or a clip). Keep the wires short and the screw terminals tight — no exposed copper may be visible.

## 13.2 Setting Up the Shelly (Input Mode)

After the first power-on, you set up the Shelly once (via its own app or web interface):

1 Connect the Shelly to Wi-Fi (per the Shelly's instructions).

2 Set Input Mode = Switch (Follow) — this makes the relay follow the SW signal exactly.

3 Done: from now on, the ESP determines how long the load runs, via the PhotoMOS.

# 14 Assembly and Commissioning

## 14.1 Assembling and Preparing the ESP

The small parts are soldered (Chapter 9). Now the ESP:

## 14.2 The USB-Only Test

✓ Everything Important Works Without Mains Power Power the ESP via USB (no mains!). Check:

A button press starts the countdown on the OLED.
The plugged-in OLED shows the clock/status.
The PhotoMOS output switches: measure with a multimeter at the PhotoMOS output (continuity, while the timer is running).

Only once all of this checks out does mains voltage come into play.

Flash the ESP via USB and test the Wi-Fi connection (Chapters 10 and 11) — this is easiest before it is soldered in.

1

2 Solder the ESP onto the board (pin headers or directly).

•
•
•

## 14.3 The First Mains Test

Never Open While Powered
The mains test only runs with the enclosure closed. Always de-energize before making changes.

Visual inspection: no solder bridges, no short circuit between L/N, ≥ 6 mm clearance everywhere between 230 V and low voltage.

1

2 Solder in the power supply, connect the Shelly (Chapter 13), wire up the load.

3 Close the enclosure.

4 Switch on via an RCD/PRCD. The OLED shows the clock/status.

5 Set up the Shelly (Input Mode "Switch"), then run a button test with the load.

6 | Set the times as desired via | http://feeder-relais.local .

# 15 Firmware Updates and Maintenance

## 15.1 Wireless Updates (OTA)

After the initial USB flash, two wireless update paths are set up — the USB port is welcome to be hard to reach once the device is installed:

Network OTA: esphome run firmware/timer-relais-c3.yaml updates over Wi-Fi.
Web upload: in the Service tab, upload feeder-relais.ota.bin . The device then restarts.

ℹ Wi-Fi Data Is Preserved
An update only overwrites the program, not the stored settings. Wi-Fi, timer settings, and network configuration survive the update.

## 15.2 The Service Log

With live view enabled, the Service tab shows the most recent log lines, filtered by level (ERROR/WARN/INFO/DEBUG). This helps with troubleshooting without having to hook the ESP up to a cable. Full logs are also available via esphome logs firmware/timer-relais-c3.yaml .

•
•

# 16 Troubleshooting

## 16.1 While Flashing and Connecting

Problem | Remedy
ESP isn't recognized | Data cable instead of charge-only cable; try a different USB port
"Connect" fails | Force boot mode (hold BOOT, tap RESET, release BOOT)

feeder-relais.local
unreachable

Was Wi-Fi set up in the setup hotspot? mDNS takes a moment; try the IP address directly (in the OLED menu)

Setup hotspot missing | The device is already connected to a Wi-Fi network; otherwise do a
factory reset (factory image with flash erase)

## 16.2 During Operation

Problem | Remedy
OLED stays dark | Is the display seated correctly on J4? Check the GND/VCC/SCL/SDA pinout

Clock shows
"--:--"

no time from the NTP server yet; check Wi-Fi and the NTP server

Status dot red | OLED unreachable or no Wi-Fi — the Status tab shows details
Load doesn't switch | Is the Shelly set to "Switch/Follow"? Check the SW/O wiring; measure the PhotoMOS output in the USB-only test
Button doesn't trigger | Is the button seated exactly under the plunger? Check the solder joints

# 17 Appendix: Pinouts, Files, Glossary

## 17.1 Pinout and Net List

ESP pin | Function | Net
5V / G | Supply | +5V / GND
3V3 | OLED supply | +3V3
GPIO3 / 4 / 5 | Buttons T1 / T2 / T3 | BTN1/2/3
GPIO6 | PhotoMOS driver (via 330 Ω) | PMOS_DRV
GPIO7 | I²C SDA (OLED) | SDA
GPIO8 | Onboard RGB status LED | —
GPIO9 | I²C SCL (OLED) | SCL

The five 230 V nets (net class "230V"): L_IN , L_F , N , SW_SHELLY , O_LAST .

## 17.2 Project Files

Path | Content
kicad-v3/ | the v3 board (KiCad: schematic, layout, rules) +
| manufacturing data
box/feeder_back.scad | enclosure back piece (OpenSCAD source) + ready-made STL

box/Timer-Ersatzplatine-v3-

BOARD.stl | board mock-up for the fit check
firmware/timer-relais-c3.yaml | ESPHome firmware
firmware/timer_web.h | web app + JSON interface
firmware/net_config.h | network configuration (IP, NTP, hostname, roaming, language)
firmware/build/*.bin | ready-made flash images (factory + ota)
README.md | project overview (German; translations under docs/ <language>/ )
docs/handbuch/…-Handbuch.pdf | this manual as a PDF (translations under docs/<language>/ )

## 17.3 Glossary

Term | Meaning
ESP32-C3 | small microcontroller with Wi-Fi — the device's "brain"
PhotoMOS | semiconductor relay that isolates low voltage and 230 V using light
Shelly | ready-made Wi-Fi switching relay with power measurement (external)
OLED | small, high-contrast display
Gerber | standard file format for PCB manufacturing
Footprint | the solder pattern of a component on the board
DRC | Design Rules Check — the automatic rule check in KiCad
Creepage distance | the path along the surface that current can "creep" along
OTA | "Over the Air" — wireless firmware update
NTP | internet time service that sets the clock

## 17.4 License and Thanks

This manual is licensed under CC BY-NC-SA 4.0. Its structure follows the documentation rulebook of the sister project AskSin-Analyzer: a table of contents with jump targets, fixed page-break rules, and the footer with the way back to the contents on every page.

Building this project is at your own risk. 230 volts can be fatal — when in doubt, consult a qualified electrician.

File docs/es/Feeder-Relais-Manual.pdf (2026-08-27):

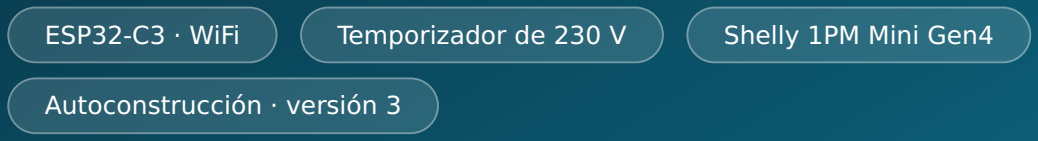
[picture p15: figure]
ESP32-C3 · WiFi; Temporizador de 230 V; Shelly 1PM Mini Gen4; Autoconstrucción · versión 3

# Feeder-Relais

## El manual — de la placa vacía al dispositivo terminado dentro de su carcasa


Edición 1 · agosto de 2026 · español

Hardware v3 · firmware ESPHome · CC BY-NC-SA 4.0

# Acerca de este manual

Este manual está dirigido a personas principiantes. No necesitas formación en electrónica — pero sí un soldador, algo de paciencia y la disposición a teclear algunos comandos en una terminal. Cada paso está descrito por completo: qué haces, por qué lo haces y cómo reconoces que ha funcionado. Al final tendrás en tus manos un dispositivo que enciende una carga de 230 V (por ejemplo, un comedero automático) pulsando un botón durante un tiempo ajustable — manejable mediante tres botones, una pequeña pantalla y una página web en la red doméstica.

Este dispositivo lleva 230 voltios
230 voltios de tensión de red son mortales. El montaje, la comprobación y la puesta en marcha de la fuente de alimentación deben quedar en manos de un electricista cualificado o de una persona instruida. Todas las pruebas que se pueden realizar sin personal cualificado se llevan a cabo en este manual exclusivamente por USB y sin ninguna tensión de red. Por favor, lee primero el capítulo 2.

Cómo leer este manual

ℹ Nota
Los recuadros azules aportan conocimientos de fondo. Se pueden saltar — pero hacen que muchas cosas se entiendan mejor.

✓ Consejo
Los recuadros verdes ahorran tiempo o disgustos.

⚠ Atención
Los recuadros amarillos señalan puntos en los que suele fallar algo.

Alto
Los recuadros rojos señalan acciones que pueden destruir el hardware o herirte. Léelos siempre.

Los comandos para la terminal se ven así — se introducen línea por línea y se envían con
Enter . Las líneas que empiezan por | # | son comentarios y no se escriben:

# Esto es un comentario — solo a modo de explicación

esphome run firmware/timer-relais-c3.yaml
© 2026 S. Sternitzke · CC BY-NC-SA 4.0 | ↑ Contenido | Feeder-Relais · Manual Edición 1

Las referencias como «capítulo 7» son pulsables en el PDF. A través del enlace «↑ Contenido» en el pie de cada página puedes volver en cualquier momento a la vista general.

# Contenido

### 1 Qué es el Feeder-Relais

### 2 Seguridad — leer primero

### 3 Cómo funciona el sistema

### 4 Lista de compras: material y herramientas

### 5 La carcasa

### 6 Entender la placa

### 7 Mandar fabricar la placa

### 8 KiCad paso a paso (solo si haces cambios propios)

### 9 Montar los componentes de la placa

### 10 Cargar el firmware

### 11 Configurar el WiFi y manejar desde el navegador

### 12 Red, idioma y pantalla

### 13 Conectar el Shelly externo

### 14 Montaje y puesta en marcha

### 15 Actualizaciones de firmware y mantenimiento

### 16 Resolución de problemas

### 17 Anexo: asignaciones, archivos, glosario

# 1 Qué es el Feeder-Relais

El Feeder-Relais es una placa de control autoconstruida que enciende una carga de 230 voltios pulsando un botón durante un tiempo ajustable y luego se apaga sola. El nombre proviene de su uso original: sustituye la placa temporizadora defectuosa de un comedero automático (en inglés feeder). Como al final solo «pulsa un interruptor durante un tiempo determinado», sirve para cualquier carga que se quiera conmutar de forma temporizada.

## 1.1 Qué hace el dispositivo

En la parte delantera hay tres pulsadores. Una pulsación corta enciende la carga durante un tiempo predefinido:

Botón | Rótulo | Tiempo por defecto | ajustable
S1 | Down / Manual (T1) | 5 segundos | 1–600 s por WiFi
S2 | SET (T2) | 10 segundos | 1–600 s por WiFi
S3 | UP (T3) | 15 segundos | 1–600 s por WiFi

Una pequeña pantalla OLED detrás de la ventana muestra arriba la recepción WiFi, la hora grande (ajustada mediante un servidor de hora de internet) y el estado Idle; abajo, la fecha y la memoria libre. Cuando un temporizador está en marcha, en el centro aparece la cuenta atrás en segundos y a la derecha Feed.

El manejo funciona sin app y sin nube mediante una pequeña página web optimizada para móviles que el propio ESP32 proporciona (en el navegador http://feeder-relais.local ): activar el temporizador, ajustar los tiempos, consultar los valores de red y estado. Para la conexión con una domótica (por ejemplo ioBroker o Home Assistant) existe además una interfaz JSON ligera (capítulo 11).

## 1.2 La cadena de señal

Desde que se pulsa el botón hasta que se conmuta la carga, la señal recorre cinco etapas. Cada una tiene una única función:

Botón ─► ESP32-C3 ─► 330 Ω ─► PhotoMOS ─► Shelly 1PM ─► Carga
S1–S3 | cuenta el | limita la | conmuta con | conmuta y | (bomba,
| tiempo, | corriente | aislamiento | mide la carga | motor de
| dibuja el | del LED | galvánico | de 230 V | alimentación,
| OLED | | | | ventilador …)

ℹ ¿Por qué tantas etapas?
El ESP32 trabaja con unos inofensivos 3,3 voltios. No debe «tocar» nunca 230 voltios directamente. El PhotoMOS es el puente: separa por completo la baja tensión y la tensión de red mediante luz (detalles en el capítulo 3). El Shelly se encarga de la conmutación propiamente dicha de la carga y además mide la potencia.

## 1.3 Qué cambia la versión 3

Este manual describe la versión 3 de la placa. Respecto a la primera versión, la construcción se ha simplificado notablemente:

El Shelly está fuera de la placa y se conecta mediante un borne (capítulo 13). Esto mantiene la placa pequeña y la tensión de red bien organizada.
Toda la electrónica está en la cara posterior de la placa. En la parte delantera solo quedan los tres pulsadores y la conexión de la pantalla — es decir, todo lo que se maneja o se ve a través del panel frontal.
La placa tiene cuatro capas con planos de masa continuos. Esto la hace poco propensa a interferencias y permite una separación limpia entre tensión de red y baja tensión (capítulo 6).
La parte trasera de la carcasa se imprime en 3D (capítulo 5) y tiene la profundidad suficiente para alojar la placa y el Shelly.

•

•

•

•

# 2 Seguridad — leer primero

Peligro de muerte por 230 voltios
La tensión de red puede ser mortal. Quien monte, compruebe y ponga en marcha el lado de 230 V debe conocer los peligros y dominar las reglas de la electrotecnia. En caso de duda: recurrir a un electricista cualificado. No hay excepción ni prisa que lo justifique.

## 2.1 Las reglas básicas

Todas las primeras pruebas de funcionamiento del ESP, los pulsadores y el OLED se realizan exclusivamente por USB — sin ninguna tensión de red conectada.
La primera prueba con 230 V se realiza detrás de un interruptor diferencial (RCD/PRCD, «enchufe de protección personal»), con la carcasa cerrada. Nunca manipular el dispositivo abierto y bajo tensión.
Delante de la fuente de alimentación deben ir un fusible de precisión (1 A lento) y un varistor. Los pequeños módulos AC/DC no incorporan ninguno de los dos por sí mismos. En la placa rige, entre cada línea de 230 V y la baja tensión, una distancia mínima de 6 mm (distancia de fuga). El motivo se explica en el apartado 2.2.
Para el relé PhotoMOS es obligatorio usar un tipo con ≥ 400 V de tensión de bloqueo (capítulo 3). Un optoacoplador corriente no es admisible aquí.

•

•

•

•

•

## 2.2 Por qué 6 milímetros de distancia

Entre dos superficies de cobre en una placa, la corriente no solo puede saltar por el aire, sino también «arrastrarse» a lo largo de la superficie — favorecida por el polvo, la humedad y la suciedad. Esta «distancia de fuga» debe ser lo bastante grande a 230 voltios. La fijamos en

### 6 mm; es un valor generoso y deja margen. La única excepción permitida es el interior del

propio relé PhotoMOS — este componente es el punto de aislamiento certificado y puede llevar tensión de red y baja tensión a pocos milímetros de distancia (capítulo 6).

⚠ La regla de los 6 mm no es una recomendación
Está establecida en el diseño de la placa como una regla de comprobación fija (capítulos 6 y 8). Quien modifique la placa no puede relajar esta regla — es la razón por la que el dispositivo sigue siendo seguro en el uso diario.

## 2.3 El camino seguro hacia la primera puesta en marcha

El orden de este manual se ha elegido deliberadamente para que hagas lo peligroso al final y puedas practicar sin riesgo hasta entonces:

Montar los componentes de la placa y flashear el ESP sin fuente de alimentación por USB (capítulos 9 y 10).

1

Prueba solo por USB: los pulsadores, el OLED y la salida del PhotoMOS se comprueban completamente sin tensión de red (capítulo 14).

2

Solo cuando todo funcione se añaden la fuente de alimentación y el Shelly — y la primera prueba con tensión de red se realiza detrás de un RCD con la carcasa cerrada
(capítulo 14).

3

# 3 Cómo funciona el sistema

## 3.1 Los componentes y sus funciones

Componente | Función
ESP32-C3 Super Mini | El «cerebro». Un pequeño microcontrolador con WiFi. Lee los pulsadores, cuenta el tiempo, dibuja el OLED, sirve la página web y controla el PhotoMOS. Alimentado con 5 V, funciona internamente con 3,3 V.
Relé PhotoMOS | El punto de aislamiento galvánico entre 3,3 V y 230 V. Detalles en el apartado 3.3.
Resistencia limitadora 330 Ω | Limita la corriente a través del LED interno del PhotoMOS, para que no se sobrecargue.
Fuente de alimentación (módulo AC/DC) | Convierte los 230 V~ en los 5 V con los que funciona el ESP. Un módulo terminado y encapsulado.

Shelly 1PM Mini
Gen4

Conmuta la carga propiamente dicha, mide la potencia y además es accesible por WiFi. Se encuentra fuera de la placa.

Pantalla OLED de
0,91"

Muestra la hora, la cuenta atrás y el estado. Solo se enchufa, no se suelda.

Fusible + varistor | Protegen contra sobrecorriente y sobretensión en el lado de red.

## 3.2 Por qué un Shelly — y por qué fuera de la placa

El Shelly 1PM Mini Gen4 es un relé de conmutación terminado y probado, con medición de potencia. Usarlo tiene tres ventajas: la conmutación arriesgada de la carga la asume un producto certificado ya fabricado; la potencia se mide (se ve si la carga realmente está funcionando); y el propio Shelly es accesible por WiFi, por si se quiere integrar adicionalmente.

Nuestra placa solo «pulsa el interruptor» del Shelly — como una señal de hardware real, sin dependencia del WiFi para la función principal. En la versión 3, el Shelly está fuera de la placa y se conecta mediante un borne (capítulo 13). Esto mantiene la placa pequeña, los tramos de 230 V cortos y el montaje ordenado.

ℹ «Switch / Follow»
El Shelly se configura para que su relé esté encendido exactamente el tiempo que nuestra señal esté activa (modo Switch o Follow). Con ello, toda la temporización sigue en manos del ESP — el Shelly solo obedece.

## 3.3 Qué es un PhotoMOS y por qué precisamente este

Un PhotoMOS es un diminuto relé de semiconductor. En un lado hay un LED, que el ESP controla con 3,3 V. En el otro lado hay un interruptor controlado por luz, que puede conmutar tensión de red. Entre ambos solo hay luz — es decir, un aislamiento galvánico completo entre baja tensión y 230 V.

La entrada de conmutación del Shelly está referida a la tensión de red (espera una L conmutada). Por eso el PhotoMOS debe soportar ≥ 400 V de tensión de bloqueo — por ejemplo un Omron G3VM-601BY o un Panasonic AQY216.

Nada de PC817 ni similares
Un optoacoplador corriente (por ejemplo el PC817) no está permitido para el lado de red — no soporta la tensión de forma segura y no está construido para aislar tensión de red. Usar únicamente un PhotoMOS apto para tensión de red con ≥ 400 V.

## 3.4 Cada componente en detalle

Aquí tienes la función exacta de cada componente — con los valores que realmente se han montado en la placa v3. Las referencias (designadores) aparecen así en la serigrafía de montaje de la placa.

Referencia | Valor | Función exacta
U1 | ESP32-C3 Super Mini | El microcontrolador con WiFi. Funciona con 5 V, genera internamente 3,3 V mediante un regulador (también para el OLED). Incorpora un LED RGB integrado (WS2812) en GPIO8. Controla los pulsadores, el OLED, el PhotoMOS y la interfaz web.
K1 | G3VM-601AY2 | El PhotoMOS — el aislamiento galvánico entre 3,3 V y 230 V. Pines 1/2 = LED interno (pin 1 a través de R1 desde GPIO6, pin 2 a GND), pines 3/4 = interruptor controlado por luz (pin 3 = L_F, pin 4 = SW_SHELLY). Tensión de bloqueo ≥ 400 V.
R1 | 330 Ω | Resistencia limitadora del LED de K1. De ~3,3 V menos ~1,2 V de tensión directa del LED fluyen unos 6 mA — suficiente para una conmutación segura, muy por debajo del límite del LED.
PS1 | TSP-05 (5 V / 3 W) | La fuente de alimentación: convierte 230 V~ (L_F + N) en los 5 V/ GND para el ESP. 3 W = 600 mA — suficiente para los picos de transmisión WiFi (~350 mA) más el OLED.
C1 | 220 µF / 10 V | Condensador de apoyo en +5 V: amortigua picos breves de corriente al transmitir por WiFi y evita la caída de tensión que de otro modo reiniciaría el ESP.
C2 | 100 nF | Condensador de desacoplo directamente en +5 V/GND: absorbe interferencias de alta frecuencia cerca del chip.
F1 | 1 A lento | Fusible de precisión (5×20 mm) en serie: X1 (L_IN) → F1 → L_F. Protege ante cortocircuito/sobrecorriente. «Lento», para que la corriente de arranque de la fuente de alimentación no lo dispare por error.
RV1 | S14K275 (varistor) | Protección contra sobretensión en paralelo entre L_F y N: limita picos de tensión (transitorios de conmutación, interferencias de red) y protege la fuente de alimentación y la electrónica.
J2 | OLED SSD1306 128×32 | La pantalla. Dirección I²C 0x3C, 400 kHz. Solo se enchufa (asignación GND/VCC/SCL/SDA).
SW1–3 | Pulsador 6×6 mm | Los tres micropulsadores T1/T2/T3. Una conexión a GND, la otra a GPIO3/4/5 — el ESP usa pull-ups internos, una pulsación lleva el pin a GND.

Y los bornes de conexión en el borde de la placa:

Referencia | Conexión | Asignación
X1 | Entrada de red | 1 = N, 2 = L_IN (230 V entrante)
X2 | Salida de carga | 1 = O (conmutado), 2 = N
X3 | Snubber | 1 = O, 2 = N — para una red RC opcional en cargas inductivas
J1 | Shelly | 1 = SW, 2 = O, 3 = L, 4 = N (al Shelly externo, capítulo 13)

# 4 Lista de compras: material y herramientas

Todo lo que necesitas para un Feeder-Relais. La placa en sí la mandas fabricar (capítulo 7); los componentes se piden y se sueldan (capítulo 9).

## 4.1 Componentes en la placa

Referencia | Componente | Valor / tipo | Observación
U1 | ESP32-C3 Super Mini | 18 × 24 mm, USB-C | Controlador con WiFi
K1 | Relé PhotoMOS | Omron G3VM-601AY2 (o -601BY / Panasonic AQY216)

≥ 400 V!

PS1 | Módulo de alimentación AC/DC | 5 V / 3 W (clase HLK-PM05) | Comprobar la separación de pines
— | Pantalla OLED | 0,91" SSD1306, 128 × 32, I²C | Pines: GND VCC SCL SDA, dirección 0x3C
SW1–3 | Micropulsador | 6 × 6 mm, recorrido 1,5 mm | La posición es fija (panel frontal)
R1 | Resistencia | 330 Ω | Resistencia limitadora del LED del PhotoMOS
F1 | Fusible de precisión + portafusible | 1 A lento, 5 × 20 mm | lado primario, obligatorio
RV1 | Varistor | S14K275 | lado primario, obligatorio
C1 / C2 | Condensadores | 220 µF/10 V & 100 nF | Amortiguación de 5 V y desacoplo
X1 | Entrada de red | 2 polos (L, N) | Borne de tornillo, 230 V entrante
X2 | Salida de carga | 2 polos (O, N) | hacia la carga conmutada
X3 | Snubber | 2 polos (O, N) | red RC opcional para cargas inductivas
J1 | Conexión Shelly | 4 polos (SW, O, L, N) | hilos cortos hacia el Shelly externo, capítulo 13
J2 | Regleta hembra OLED | 1 × 4, paso 2,54 | GND/VCC/SCL/SDA, la pantalla se enchufa

## 4.2 Módulos fuera de la placa

Shelly 1PM Mini Gen4 (tipo S4SW-001P8EU), máx. 8 A / 240 V, medidas aprox. 29 × 34 × 16 mm.
Material de montaje: cinta adhesiva VHB de doble cara o un clip impreso en 3D para fijar el Shelly y la fuente de alimentación dentro de la carcasa.
Hilos cortos (p. ej. 0,75 mm²) para la conexión placa ↔ Shelly y hacia la salida de carga.

## 4.3 Herramientas

Soldador (con control de temperatura), estaño, trenza desoldadora, fundente.
Pinzas finas, alicates de corte lateral, pelacables.
Un cable de datos USB-C (atención: muchos cables baratos solo cargan) y un ordenador. Multímetro (prueba de continuidad y de tensión).
Una impresora 3D para la parte trasera de la carcasa (o un servicio de impresión).
Para la prueba con 230 V: un RCD/PRCD.

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
# 5 La carcasa

La carcasa consta de dos partes: la parte delantera (el panel frontal original con la ventana y las tres varillas pulsadoras) y la parte trasera, que imprimes tú mismo en 3D. La placa se atornilla desde atrás a seis columnas, y la pantalla se sitúa detrás de la ventana.


La parte trasera impresa en 3D con las seis columnas de tornillo y la lengüeta de suspensión (arriba).

## 5.1 Estructura: parte delantera y trasera

La parte delantera es la parte superior de la carcasa original. Lleva la ventana (detrás está el OLED) y las varillas que, al pulsarlas, accionan los tres pulsadores de la placa. Por eso la posición de los pulsadores no es negociable — deben quedar exactamente debajo de las varillas (capítulo 9).


La parte delantera (original) con la ventana y las tres varillas pulsadoras.

La parte trasera en la versión 3 es deliberadamente más profunda que el original (35 mm en lugar de los 5,7 mm originales), para que quepan cómodamente la placa y el Shelly externo. En el borde superior hay una lengüeta de suspensión con ojo de cerradura para el montaje en pared.

## 5.2 Imprimir tú mismo la parte trasera

La plantilla está como archivo OpenSCAD en el proyecto, en box/feeder_back.scad . OpenSCAD es un programa gratuito que genera un modelo 3D a partir de un archivo de texto — la ventaja: todas las medidas están como variables al principio del archivo y se pueden adaptar.

✓ Imprime primero la placa como maqueta
En el proyecto también está box/Timer-Ersatzplatine-v3-BOARD.stl — una réplica 1:1 de la placa (contorno, agujeros de tornillo, ranuras). Imprímela plana y colócala dentro de la parte trasera antes de encargar la placa real. Así compruebas sin riesgo si todo encaja (capítulo 7).

## 5.3 Presupuesto de altura y fijación

La placa se atornilla desde atrás con seis tornillos a las columnas de la parte trasera (retícula de columnas 45 mm × 70 mm, agujero de tornillo 3,2 mm, avellanado para la cabeza del tornillo en la cara posterior). Otros cuatro puntos en el panel frontal centran la placa adicionalmente.

Medida | Valor
Medida exterior parte trasera | 109,8 × 90,8 mm
Profundidad parte trasera (v3) | 35 mm
Grosor de pared y fondo | 1,3 mm
Medida de la placa | 101,6 × 77,5 mm
Retícula de columnas | 45 mm (X) × 70 mm (Y)

⚠ Nada debe sobresalir hacia abajo (hacia la parte delantera)
Entre la placa y el panel frontal el espacio es escaso. Por eso todos los componentes altos se sitúan en la cara posterior de la placa (capítulo 6). En la parte delantera solo quedan los pulsadores planos y la conexión de la pantalla.

1 Abrir OpenSCAD y cargar box/feeder_back.scad .

Con F6 calcular el modelo y guardarlo como archivo imprimible mediante Archivo → Exportar → STL. Ya se incluye un STL listo: box/feeder_back_35mm.stl .

2

Cargar el STL en el laminador (slicer) de tu impresora. Recomendación: imprimir con el lado abierto hacia arriba, 3–4 líneas de pared, 20–30 % de relleno, sin soportes necesarios.

3

# 6 Entender la placa

No tienes que diseñar la placa tú mismo — está terminada en el proyecto, en kicad-v3/ . Este capítulo explica cómo está construida, para que al montar los componentes y comprobar sepas qué va dónde. Quien quiera modificar algo por su cuenta encontrará la guía de KiCad en el capítulo 8.

## 6.1 Cara delantera y trasera

En la versión 3, toda la electrónica está en la cara posterior. En la cara delantera (hacia el panel frontal) solo quedan los tres pulsadores y el conector OLED — todo lo que se maneja o se ve.


La cara posterior lleva el ESP, la fuente de alimentación, el PhotoMOS y los bornes de 230 V. La tensión de red (abajo) y la baja tensión (arriba) están claramente separadas en el espacio.

## 6.2 Cuatro capas y los planos de masa

La placa tiene cuatro capas de cobre: las dos capas externas (cara delantera y trasera) llevan las pistas, las dos capas internas son planos de masa continuos en la zona de baja tensión. Estos planos de masa actúan como un plano de referencia estable: hacen que el montaje sea poco propenso a interferencias y que la función WiFi sea estable.

ℹ Importante para la seguridad
En la zona de tensión de red no hay cobre interior. Las líneas de 230 V discurren exclusivamente por las dos capas externas, y los planos de masa mantienen en todas partes al menos 6 mm de distancia respecto a la tensión de red. Así no puede producirse en ningún lugar del interior de la placa una proximidad peligrosa.

## 6.3 Tensión de red solo en el exterior: la regla de los 6 milímetros

Las cinco redes L_IN , L_F , N , SW_SHELLY y O_LAST llevan 230 voltios. Están agrupadas en una clase de red propia «230V» (pistas más anchas, distancias mayores) y se encuentran todas abajo a la izquierda, lejos de la electrónica. Una regla de comprobación establecida en el diseño exige 6 mm de distancia entre cada red de 230 V y cada baja tensión.

La única excepción es el relé PhotoMOS K1: su encapsulado es el punto de aislamiento certificado (pines 1/2 = baja tensión, pines 3/4 = tensión de red). Solo ahí pueden encontrarse ambos mundos a pocos milímetros — precisamente para eso está construido el componente.

## 6.4 Las redes y la asignación de pines

Qué lleva cada línea lo muestra la siguiente vista general:

Nombre de red | lleva | conecta
L_IN | 230 V (sin proteger) | Entrada de red X1 → fusible F1
L_F | 230 V (protegida) | F1 → varistor RV1, fuente PS1, PhotoMOS K1.3, Shelly J1.L
N | 230 V neutro | X1 → RV1, PS1, Shelly J1.N, carga X2, snubber X3
SW_SHELLY | 230 V conmutado | PhotoMOS K1.4 → Shelly J1.SW
O_LAST | 230 V conmutado | Shelly J1.O → salida de carga X2 + snubber X3
+5V | baja tensión | Fuente de alimentación → ESP 5V, C1, C2
GND | baja tensión | Masa: ESP, pulsadores, PhotoMOS, OLED
+3V3 | baja tensión | Salida ESP-3V3 → OLED

El ESP32-C3 utiliza estos pines:


Las conexiones utilizadas del ESP32-C3 Super Mini.

Pin | Función
5V / G | Alimentación desde la fuente
3V3 | alimenta el OLED

GPIO3 / 4 / 5 | Pulsadores T1 / T2 / T3
GPIO6 | Excitador del PhotoMOS (a través de 330 Ω)
GPIO7 | I²C-SDA (OLED)
GPIO8 | LED RGB integrado (estado)
GPIO9 | I²C-SCL (OLED)

ℹ ¿Por qué SDA en GPIO7 y no en GPIO8?
En GPIO8 está el pequeño LED RGB de estado del módulo ESP. Si ahí estuviera el I²C, el tráfico de datos controlaría el LED de forma descontrolada. Por eso SDA está en GPIO7. Ese mismo LED RGB muestra más adelante el semáforo de estado del dispositivo (capítulo 11).

## 6.5 Cada conexión del ESP con todo detalle

Esta tabla es la correspondencia vinculante entre la placa y el firmware. A la izquierda está lo que el firmware ( timer-relais-c3.yaml ) hace con el pin — con su configuración exacta; a la derecha, adónde lo lleva la placa. Ambos lados deben coincidir exactamente, o el dispositivo no funcionará.

Pin ESP | Firmware (ID y configuración) | Placa | Función en detalle
| up interno, invertido, antirrebote de 30 ms | | Pulsador S1 (Down/Manual). Nivel de reposo HIGH; una pulsación lleva a GND (LOW) → se considera «pulsado». Corta = activa el temporizador 1.
GPIO3 | btn_s1 | · entrada, pull-
Pad 3 → | /BTN1 | →
pulsador S1 a GND
GPIO4 | btn_s2 | · entrada, pull-
up, invertido, 30 ms
| | | Pad 4 → | /BTN2 | →
pulsador S2 a GND

Pulsador S2 (SET). Corta = temporizador 2; larga ≥ 3 s = menú de información.

GPIO5 | btn_s3 | · entrada, pull-
up, invertido, 30 ms
| | | Pad 5 → | /BTN3 | →
pulsador S3 a GND

Pulsador S3 (UP). Corta = temporizador 3; larga ≥ 1,2 s = detener todo.

GPIO6 | shelly_trigger | ·
salida GPIO
| | | Pad 6 →
/PMOS_DRV | →
R1 330 Ω → ánodo
del LED de K1

Controla el PhotoMOS. HIGH = LED encendido = PhotoMOS conduce = Shelly-SW recibe L → carga encendida. LOW = apagado.

GPIO7 | i2c: sda | · 400 kHz | Pad 7 → | /SDA | →
OLED J2.4

Línea de datos I²C hacia el OLED. Está deliberadamente en GPIO7 (no en GPIO8).

GPIO8 | status_led | · WS2812
(GRB), atenuado

interno al
módulo — sin red
en la placa (Pad 8
libre)

LED RGB de estado integrado (semáforo verde/amarillo/rojo). Está fijo en GPIO8 del módulo; por eso aquí no puede haber una segunda señal — la razón por la que SDA se trasladó a GPIO7.

GPIO9 | i2c: scl | · 400 kHz | Pad 9 → | /SCL | →
OLED J2.3

Línea de reloj I²C hacia el OLED (dirección 0x3C).

5V /
GND

Alimentación del
| módulo
/+5V | / | GND | de la
fuente de
alimentación

5 V del módulo AC/DC; GND es la masa común (también las capas internas).

3V3 Salida del regulador
integrado

/+3V3 → OLED-VCC

El ESP genera internamente 3,3 V y con ellos alimenta el OLED.

⚠ Precisamente esta correspondencia es decisiva
Si en la placa SDA se coloca por error en GPIO8 (donde está el WS2812), el OLED se queda negro y la señal del LED interfiere con la línea de datos. Al replicar la placa, comprobar por tanto: el OLED-SDA debe estar conectado al Pad 7 del ESP (GPIO7), el SCL al Pad 9 (GPIO9) — GPIO8 queda libre.

# 7 Mandar fabricar la placa

Una placa de cuatro capas no se hace en casa — se manda fabricar en un fabricante de placas de circuito impreso. Hoy en día es barato y sencillo: se suben un puñado de archivos y las placas terminadas llegan por correo.

## 7.1 Primero, una prueba en plástico

✓ El truco de la prueba de encaje ahorra dinero
Antes de pedir las placas, imprime en la impresora 3D el archivo adjunto box/Timer-Ersatzplatine-v3-BOARD.stl a escala 1:1 (plano, sin soportes) y colócalo dentro de la parte trasera impresa. ¿Encaja el contorno, se alinean las seis ranuras con las columnas, quedan bien los agujeros de tornillo? Estos cinco minutos te ahorran un pedido caro equivocado.

Alternativamente (o además), imprime el contorno de la placa en papel a escala 1:1 y recórtalo.

## 7.2 Generar los datos Gerber

«Gerber» es el formato de archivo estándar que esperan los fabricantes de placas — un archivo por capa, más los datos de taladrado. Los Gerber ya terminados están incluidos en el proyecto; para generarlos tú mismo desde KiCad:

1 Abrir en KiCad el proyecto kicad-v3/Timer-Ersatzplatine-v3.kicad_pcb .

Archivo → Fabricación → Archivos Gerber — seleccionar todas las capas estándar, exportar.

2

3 En el mismo diálogo, generar los archivos de taladrado (Excellon).

4 Empaquetar todos los archivos generados en un archivo ZIP.

## 7.3 Pedir a un fabricante

Sube el ZIP a un proveedor como JLCPCB, PCBWay o Aisler. Ajustes importantes:

Ajuste | Valor
Capas | 4
Grosor del material | 1,6 mm (estándar)
Acabado superficial | HASL sin plomo o ENIG
Cobre | 1 oz (35 µm)
Color | indiferente

⚠ Configurar cuatro capas
Elige realmente 4 capas. Una réplica de dos capas no tendría planos de masa internos — la resistencia al WiFi y a las interferencias sería peor, y las reglas de comprobación del diseño ya no encajarían.

# 8 KiCad paso a paso (solo si haces cambios propios)

Este capítulo lo necesitas solo si quieres modificar tú mismo la placa. Para una réplica pura puedes saltarlo — los datos de fabricación ya terminados están incluidos. KiCad es un programa gratuito para el diseño de placas (probado con KiCad 8/9/10; los nombres de menú pueden variar mínimamente).

## 8.1 Abrir el proyecto y comprobar el esquemático

## 8.2 Footprints y clases de red

Cada símbolo de componente está vinculado a un footprint — la huella de soldadura en la placa. Comprueba en Herramientas → Asignar footprints que, por ejemplo, PS1 corresponde a la fuente de alimentación realmente comprada (¡comprobar la separación de pines!) y que el PhotoMOS corresponde a la forma constructiva SMD o DIP.

Las clases de red están en el archivo del proyecto y no deben modificarse: Default (0,2 mm de distancia y anchura de pista) y 230V (1,0 mm de distancia y anchura de pista) con las cinco redes L_IN, L_F, N, SW_SHELLY, O_LAST.

1 Iniciar KiCad y abrir kicad-v3/Timer-Ersatzplatine-v3.kicad_pro .

Iniciar el editor de esquemáticos. Muestra cómo están conectados todos los componentes.

2

Ejecutar Herramientas → Comprobar reglas eléctricas (ERC). Los avisos sobre «pines de alimentación sin conectar» son conocidos y no críticos.

3

## 8.3 La regla de los 6 milímetros y el DRC

La regla de distancia de fuga está como archivo propio | Timer-Ersatzplatine-v3.kicad_dru | en
el proyecto. Exige 6 mm entre 230 V y baja tensión — con la excepción deliberada del PhotoMOS K1:

(version 1)
(rule "230V->SELV 6mm (K1-Barriere ausgenommen)" (condition "... 230-V-Netz gegen Nicht-230-V-Netz, K1 ausgenommen ...")
(constraint creepage (min 6mm))
(constraint clearance (min 6mm)))

Después de cada cambio, ejecutar el DRC (Design Rules Check, Comprobar → Comprobar reglas de diseño) hasta que quede sin errores.

⚠ Retirar los planos de masa 6 mm
El relleno automático de los planos de masa solo respeta la distancia de la clase de red, no la regla de los 6 mm. Por eso los planos de masa tienen una forma geométrica que los mantiene en todas partes a 6 mm de la tensión de red. Quien vuelva a dibujar los planos debe mantener esta distancia a mano.

## 8.4 Datos de fabricación

Si el DRC y la comprobación visual (vista 3D con Alt+3 ) están correctos, exportas los datos Gerber y de taladrado tal como se describe en el capítulo 7.

# 9 Montar los componentes de la placa

«Montar los componentes» significa: soldar las piezas a la placa. Procedemos de las piezas planas a las altas — así la placa siempre queda estable al soldar.

## 9.1 Orden y herramientas

Orden recomendado: R1 → C2 → PhotoMOS → pulsadores → conector OLED J4 → C1 → portafusible F1 → varistor RV1 → bornes. El ESP se coloca solo cuando ya se ha flasheado y probado (capítulos 10 y 14).

## 9.2 Los componentes SMD

El PhotoMOS es (según el tipo) un pequeño componente SMD. Así se suelda limpiamente:

ℹ Orientación del PhotoMOS
El pin 1 está marcado (punto o esquina biselada). El lado de baja tensión (pines 1/2) mira hacia la electrónica, el lado de tensión de red (pines 3/4) hacia la esquina de 230 V. La huella de soldadura indica la dirección — no adivinar, guiarse por la serigrafía.

1 Estañar finamente un pad.

Colocar el componente con las pinzas y fijarlo soldándolo al pad estañado — controlar la posición.

2

3 Soldar los demás pines. El fundente ayuda; los puentes se evitan usando poco estaño.

## 9.3 Los componentes con cables y los conectores

Pulsadores SW1–3: colocarlos con exactitud — más adelante deben quedar justo debajo de las varillas del panel frontal. Presionarlos a ras contra la placa y luego soldar.
Conector OLED J4: soldar la regleta hembra (1×4) de forma que quede en vertical. El OLED se enchufa más adelante, no se suelda.
Fusible, varistor, bornes: en la esquina de 230 V, con distancia respecto a la electrónica. Soldar bien, sin puntos fríos.

ℹ El OLED se enchufa, no se suelda
Al OLED le sueldas una regleta de pines (hacia atrás) que encaja en el conector J4. La pantalla queda entonces con una almohadilla de espuma fina justo contra la ventana. Así sigue siendo intercambiable y la altura de montaje se mantiene baja.

•

•

•

# 10 Cargar el firmware

El «firmware» es el programa que se ejecuta en el ESP. La primerísima vez llega al chip por cable USB. Todas las actualizaciones posteriores son inalámbricas (capítulo 15).

## 10.1 Qué necesitas

el ESP32-C3 Super Mini (todavía sin soldar),
un cable de datos USB-C — muchos cables baratos solo cargan; con ellos el chip no se detecta,
un ordenador con Google Chrome o Microsoft Edge (vía B) — o ESPHome en el ordenador (vía A).


Conectar el ESP32-C3 al ordenador mediante USB-C.

ℹ No tienes que compilar nada
En el proyecto ya hay imágenes terminadas en | firmware/build/ : | feeder-
relais.factory.bin | para el primer flasheo y | feeder-relais.ota.bin | para
actualizaciones web posteriores. No contienen ninguna credencial de WiFi — esas las configuras después de flashear (capítulo 11).

•
•

•

## 10.2 Vía A — con ESPHome

ESPHome es la herramienta con la que se compila y se carga el firmware. No hace falta un secrets.yaml — no se compilan datos de WiFi en el binario.

✓ Linux: ¿«Permission denied»?
Si se deniega el acceso a | /dev/ttyACM0 , añade tu usuario al grupo | dialout | y vuelve a
iniciar sesión:

sudo usermod -aG dialout $USER

1 Conectar el ESP por USB-C.

Ejecutar en la carpeta del proyecto:

esphome run firmware/timer-relais-c3.yaml

2

ESPHome compila, pregunta por el puerto serie (en Linux, por ejemplo, | /dev/ttyACM0 ; en
Windows, un | COMx ) y flashea.

3

Tras el reinicio, el ESP abre su punto de acceso de configuración → continuar con el capítulo 11.

4

## 10.3 Vía B — en el navegador

Para la imagen ya terminada feeder-relais.factory.bin , sin ninguna instalación:


El proceso de flasheo en el navegador mediante el flasher web.

1 | En Chrome/Edge, abrir la página | https://espressif.github.io/esptool-js/ .

2 Conectar el ESP mediante el cable de datos USB-C.

3 | Dejar la velocidad en | 115200 , pulsar Connect y elegir el puerto serie del ESP.
En Flash Address introducir | 0 , con Choose File elegir | feeder-relais.factory.bin , y
luego Program. Esperar hasta que aparezca «Hard resetting…».

4

5 Continuar con el capítulo 11.

## 10.4 Si el flasheo se atasca

Síntoma | Causa / solución
El ESP no se detecta en absoluto | Cable de carga en lugar de cable de datos → probar otro cable USB-C, otro puerto

No aparece ningún puerto en el
navegador

Usar Chrome/Edge; en Windows, comprobar controladores (CH340/CP210x)

«Connect» falla | | Modo boot: mantener pulsado BOOT + pulsar RESET + soltar BOOT, y volver a conectar
Después no aparece | ….local | configurar primero el WiFi (capítulo 11); mDNS necesita un momento

# 11 Configurar el WiFi y manejar desde el navegador

## 11.1 El punto de acceso de configuración

El firmware no incluye deliberadamente ninguna credencial de WiFi. Tras flashear, el ESP abre su propio punto de acceso:

ℹ Se configura una vez, y ya no hace falta más
Los datos de WiFi se guardan en una clave de almacenamiento fija y sobreviven a las actualizaciones de firmware. Para un restablecimiento de fábrica, flashea la imagen factory con «Erase all flash».

En el móvil/ordenador, conectarse a la red WiFi «Feeder-Relais Setup» (contraseña feeder1234 ).

1

2 | Se abre una ventana de acceso (si no, ir a | http://192.168.4.1 ).

Elegir tu WiFi doméstico, introducir la contraseña, guardar — el ESP se reinicia y se
| conecta.

3

4 | A partir de ahora accesible en | http://feeder-relais.local .

## 11.2 La interfaz web

http://feeder-relais.local abre una aplicación web móvil con cinco pestañas:

Inicio: tres botones grandes (activan T1/T2/T3), cuenta atrás en vivo y Parar.
Tiempos: arriba, la selección de idioma (Deutsch/English/Français); debajo, los tres tiempos de temporizador (1–600 s), guardados de forma permanente.
Red: WiFi, modo IP DHCP/estático, servidor NTP, hostname, roaming WiFi, reinicio (capítulo 12).
Estado: versión, tiempo de funcionamiento, memoria libre, WiFi con barras de señal, IP/ MAC, motivo del último reinicio, estado del relé.
Servicio: registro en vivo, actualización de firmware y reinicio (capítulo 15).

## 11.3 El semáforo de estado y la interfaz JSON

En la cabecera hay un punto de estado: verde = todo en orden, amarillo = un temporizador está en marcha, rojo = fallo en reposo (p. ej. OLED inaccesible o sin WiFi). Ese mismo semáforo lo muestra en el dispositivo el LED RGB integrado atenuado.

Para la domótica, el ESP ofrece una interfaz JSON. Los puntos finales más importantes:

Llamada | Efecto
GET /api/status | todos los valores en JSON (activo, tiempo restante, relé, tiempos, WiFi …)
POST /api/trigger?button=N | activa el pulsador N (1–3) con su tiempo
POST /api/trigger?seconds=N | conmuta ad hoc durante N segundos
POST /api/trigger? seconds=N&src=adapter | como arriba, marca el origen — aparece como trg (button/ api/adapter) en el estado y el registro
POST /api/stop | apaga de inmediato
POST /api/config? time1=A&time2=B&time3=C | fija los tiempos (1–600 s cada uno)

ℹ Ejemplo con ioBroker
Fijar el tiempo del pulsador 1 en 8 segundos: POST http://feeder-relais.local/api/config?time1=8 .

•
•

•

•

•

# 12 Red, idioma y pantalla

## 12.1 Ajustes de red

En la pestaña Red configuras:

Modo IP: DHCP (por defecto) o estático (con IP/puerta de enlace/máscara/DNS). La IP estática se aplica en la siguiente conexión y queda activa tras un reinicio.
Servidor NTP: el servidor de hora con el que se ajusta el reloj (por defecto de.pool.ntp.org ).
Hostname: el nombre en la red (por defecto feeder-relais ). Se cambia en tiempo de ejecución — la dirección ….local es válida de inmediato.

## 12.2 Roaming WiFi

El interruptor Roaming WiFi (802.11k/v) solo tiene sentido si tienes varios puntos de acceso con el mismo SSID (Mesh/UniFi) y estos soportan la tecnología. Entonces el dispositivo puede cambiar de forma dirigida al punto de acceso más fuerte. Por defecto: desactivado. Tras cambiar el ajuste, el botón «Reconectar ahora» ayuda a que surta efecto de inmediato.

## 12.3 Manejo con los botones y el OLED

En el dispositivo, los botones están rotulados: S1 = Down/Manual, S2 = SET, S3 = UP.

pulsación corta S1 / S2 / S3 → activa el temporizador 1 / 2 / 3 con el tiempo configurado. pulsación larga UP (S3) ≥ 1,2 s → detiene todos los temporizadores, apaga.
pulsación larga SET (S2) ≥ 3 s → abre un menú de información (solo consulta: WiFi, IP, hora, sistema). S1/S3 navegan, SET corta cierra.

El OLED (128 × 32) muestra arriba la barra de WiFi, la hora grande o la cuenta atrás y el estado (Idle/Feed); abajo, la fecha y la memoria libre. El día de la semana, el estado y los títulos de menú siguen el idioma configurado. Hasta la primera sincronización de hora aparece «--:--».

•

•

•

•
•
•

# 13 Conectar el Shelly externo

Cablear solo sin tensión
El Shelly lleva 230 voltios. Todos los trabajos de cableado se realizan sin tensión, con el enchufe de red desconectado o el interruptor automático apagado — y, en caso de duda, por un electricista cualificado.

## 13.1 Cableado

El Shelly tiene cuatro bornes: L, N, SW (entrada de conmutación) y O (salida de carga). Cuatro hilos cortos lo conectan con el borne de la placa J1:

Placa (J1) | → Shelly | Significado
J1.3 (L_F) | L | Fase (protegida)
J1.4 (N) | N | Neutro
J1.1 (SW_SHELLY) | SW | nuestra señal conmutada (desde el PhotoMOS)
J1.2 (O_LAST) | O | carga conmutada hacia la salida

El Shelly se fija tumbado dentro de la carcasa (cinta VHB o clip). Los hilos deben ser cortos y los bornes de tornillo firmes — ningún cobre debe quedar al descubierto.

## 13.2 Configurar el Shelly (modo de entrada)

Tras el primer encendido, configuras el Shelly una única vez (mediante su propia app o interfaz web):

1 Conectar el Shelly al WiFi (instrucciones del Shelly).

2 Ajustar Input Mode = Switch (Follow) — así el relé sigue exactamente la señal SW.

Listo: a partir de ahora el ESP determina, a través del PhotoMOS, cuánto tiempo funciona la carga.

3

# 14 Montaje y puesta en marcha

## 14.1 Montar los componentes y preparar el ESP

Las piezas pequeñas ya están soldadas (capítulo 9). Ahora el ESP:

## 14.2 La prueba solo por USB

✓ Todo lo importante funciona sin tensión de red Alimenta el ESP por USB (¡sin red!). Comprueba:

Una pulsación de botón inicia la cuenta atrás en el OLED.
El OLED enchufado muestra la hora/el estado.
La salida del PhotoMOS conmuta: medir con el multímetro en la salida del PhotoMOS (continuidad, mientras el temporizador está en marcha).

Solo cuando todo esto sea correcto entra en juego la tensión de red.

Flashear el ESP por USB y probar la conexión WiFi (capítulos 10 y 11) — esto es más cómodo antes de soldarlo.

1

2 Soldar el ESP a la placa (regletas de pines o directamente).

•
•
•

## 14.3 La primera prueba con tensión de red

Nunca abierto bajo tensión
La prueba con tensión de red se realiza solo con la carcasa cerrada. Para hacer cambios, siempre desconectar primero la tensión.

Inspección visual: sin puentes de estaño, sin cortocircuito entre L/N, en todas partes ≥ 6 mm de distancia entre 230 V y baja tensión.

1

2 Soldar la fuente de alimentación, conectar el Shelly (capítulo 13), conectar la carga.

3 Cerrar la carcasa.

4 Encender a través de un RCD/PRCD. El OLED muestra la hora/el estado.

5 Configurar el Shelly (Input Mode «Switch»), luego una prueba de botón con carga.

6 | Ajustar los tiempos a tu gusto en | http://feeder-relais.local .

# 15 Actualizaciones de firmware y mantenimiento

## 15.1 Actualizaciones inalámbricas (OTA)

Tras el primer flasheo por USB quedan configuradas dos vías de actualización inalámbrica — el puerto USB puede quedar tranquilamente poco accesible una vez montado:

OTA por red: esphome run firmware/timer-relais-c3.yaml actualiza por WiFi.
Subida web: en la pestaña Servicio, subir feeder-relais.ota.bin . El dispositivo se reinicia después.

ℹ Los datos de WiFi se conservan
Una actualización solo sobrescribe el programa, no los ajustes guardados. El WiFi, los tiempos y la configuración de red sobreviven a la actualización.

## 15.2 El registro de servicio

La pestaña Servicio muestra, con la vista en vivo activada, las últimas líneas del registro, filtradas por nivel (ERROR/WARN/INFO/DEBUG). Esto ayuda a la resolución de problemas sin tener que conectar el ESP por cable. Los registros completos también están disponibles mediante esphome logs firmware/timer-relais-c3.yaml .

•
•

# 16 Resolución de problemas

## 16.1 Al flashear y conectar

Problema | Solución
El ESP no se detecta | Cable de datos en lugar de cable de carga; probar otro puerto USB
«Connect» falla | Forzar el modo boot (mantener BOOT, pulsar RESET, soltar BOOT)

feeder-relais.local no

accesible | ¿Se configuró el WiFi en el punto de acceso de configuración? mDNS tarda un momento; probar la IP directamente (en el menú del OLED)
Falta el punto de acceso de configuración | El dispositivo ya está conectado a un WiFi; si no, restablecimiento de fábrica (imagen factory con borrado de flash)

## 16.2 Durante el funcionamiento

Problema | Solución
El OLED permanece oscuro | ¿Está la pantalla bien colocada en J4? Comprobar la asignación GND/VCC/SCL/ SDA
El reloj muestra «--:--» | todavía no hay hora del servidor NTP; comprobar el WiFi y el servidor NTP
Punto de estado rojo | OLED inaccesible o sin WiFi — la pestaña Estado muestra detalles
La carga no conmuta | ¿Shelly en «Switch/Follow»? Comprobar el cableado SW/O; medir la salida del PhotoMOS en la prueba solo por USB
El botón no activa nada | ¿Está el pulsador exactamente debajo de la varilla? Comprobar las soldaduras

17 Anexo: asignaciones, archivos,

# glosario

## 17.1 Asignación de pines y lista de redes

Pin ESP | Función | Red
5V / G | Alimentación | +5V / GND
3V3 | Alimentación del OLED | +3V3
GPIO3 / 4 / 5 | Pulsadores T1 / T2 / T3 | BTN1/2/3
GPIO6 | Excitador del PhotoMOS (a través de 330 Ω) | PMOS_DRV
GPIO7 | I²C-SDA (OLED) | SDA
GPIO8 | LED RGB de estado integrado | —
GPIO9 | I²C-SCL (OLED) | SCL

Las cinco redes de 230 V (clase de red «230V»): L_IN , L_F , N , SW_SHELLY , O_LAST .

## 17.2 Archivos del proyecto

Ruta | Contenido
kicad-v3/ | la placa v3 (KiCad: esquemático, layout, reglas) + datos de
| fabricación
box/feeder_back.scad | parte trasera de la carcasa (fuente OpenSCAD) + STL
| terminado

box/Timer-Ersatzplatine-v3-

BOARD.stl | maqueta de la placa para la prueba de encaje
firmware/timer-relais-c3.yaml | firmware ESPHome
firmware/timer_web.h | aplicación web + interfaz JSON
firmware/net_config.h | configuración de red (IP, NTP, hostname, roaming, idioma)
firmware/build/*.bin | imágenes de flasheo terminadas (factory + ota)
README.md | resumen del proyecto (alemán; traducciones en docs/ <idioma>/ )
docs/handbuch/…-Handbuch.pdf | este manual en PDF (traducciones en docs/<idioma>/ )

## 17.3 Glosario

Término | Significado
ESP32-C3 | pequeño microcontrolador con WiFi — el «cerebro» del dispositivo
PhotoMOS | relé de semiconductor que separa baja tensión y 230 V mediante luz
Shelly | relé de conmutación WiFi terminado con medición de potencia (externo)
OLED | pantalla pequeña de alto contraste
Gerber | formato de archivo estándar para la fabricación de placas
Footprint | la huella de soldadura de un componente en la placa
DRC | Design Rules Check — la comprobación automática de reglas en KiCad
Distancia de fuga | el camino a lo largo de la superficie por el que la corriente puede «arrastrarse»
OTA | «Over the Air» — actualización de firmware inalámbrica
NTP | servicio de hora de internet que ajusta el reloj

## 17.4 Licencia y agradecimientos

Este manual está bajo CC BY-NC-SA 4.0. Su estructura sigue el reglamento de documentación del proyecto hermano AskSin-Analyzer: un índice con enlaces, reglas de salto de página fijas y el pie de página con el camino de vuelta al índice en cada página.

La réplica se realiza bajo la responsabilidad propia de cada persona. 230 voltios son mortales — en caso de duda, consultar a un electricista cualificado.

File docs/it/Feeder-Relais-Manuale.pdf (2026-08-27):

ESP32-C3 · Wi-Fi | Timer 230 V | Shelly 1PM Mini Gen4

Autocostruzione · Versione 3

# Feeder-Relais

## Il manuale — dalla scheda vuota al dispositivo finito nel suo involucro


Edizione 1 · agosto 2026 · italiano | Hardware v3 · Firmware ESPHome · CC BY-NC- SA 4.0

# Informazioni su questo manuale

Questo manuale è rivolto a chi è alle prime armi. Non serve una formazione in elettronica — ma servono un saldatore, un po' di pazienza e la disponibilità a digitare qualche comando in un terminale. Ogni passaggio è descritto per intero: cosa fai, perché lo fai e da cosa riconosci che ha funzionato. Alla fine avrai in mano un dispositivo che accende un carico a 230 V (per esempio un distributore automatico di mangime) alla pressione di un pulsante per un tempo impostabile — utilizzabile con tre pulsanti, un piccolo display e una pagina web nella rete domestica.

Questo dispositivo porta 230 volt
230 volt di tensione di rete sono pericolosi per la vita. La realizzazione, il collaudo e la messa in servizio dell'alimentatore vanno affidati a un elettricista qualificato o a una persona istruita. Tutti i test possibili senza personale qualificato avvengono in questo manuale esclusivamente via USB e senza alcuna tensione di rete. Leggi prima il capitolo 2.

Come leggere questo manuale

ℹ Nota
I riquadri blu forniscono informazioni di base. Si possono saltare — ma rendono molte cose più comprensibili.

✓ Consiglio
I riquadri verdi fanno risparmiare tempo o nervi.

⚠ Attenzione
I riquadri gialli segnalano i punti in cui capita spesso che qualcosa vada storto.

Stop
I riquadri rossi segnalano operazioni che possono distruggere l'hardware o ferire chi le compie. Leggerli sempre.

I comandi per il terminale si presentano così — vanno digitati riga per riga e confermati con
Enter . Le righe che iniziano con | # | sono commenti e non vanno digitate:

# Questo è un commento — solo a scopo esplicativo

esphome run firmware/timer-relais-c3.yaml
© 2026 S. Sternitzke · CC BY-NC-SA 4.0 | ↑ Indice | Feeder-Relais · Manuale edizione 1

I rimandi come «Capitolo 7» sono cliccabili nel PDF. Tramite il link «↑ Indice» in fondo a ogni pagina puoi tornare in qualsiasi momento alla panoramica.

# Indice

### 1 Cos'è il Feeder-Relais

### 2 Sicurezza — leggere per prima cosa

### 3 Come funziona il sistema

### 4 Lista della spesa: materiali e utensili

### 5 L'involucro

### 6 Capire la scheda

### 7 Far produrre la scheda

### 8 KiCad passo dopo passo (solo per modifiche personali)

### 9 Montare i componenti sulla scheda

### 10 Caricare il firmware

### 11 Configurare il Wi-Fi e usare il browser

### 12 Rete, lingua e display

### 13 Collegare lo Shelly esterno

### 14 Assemblaggio e messa in servizio

### 15 Aggiornamenti del firmware e manutenzione

### 16 Risoluzione dei problemi

### 17 Appendice: assegnazioni, file, glossario

# 1 Cos'è il Feeder-Relais

Il Feeder-Relais è una scheda di controllo autocostruita che accende un carico a 230 volt alla pressione di un pulsante per un tempo impostabile e poi si spegne da sola. Il nome deriva dall'impiego originario: sostituisce la scheda timer difettosa di un distributore automatico di mangime (in inglese feeder). Poiché alla fine si limita a «premere un interruttore per un certo tempo», è adatta a qualsiasi carico che si voglia commutare in modo temporizzato.

## 1.1 Cosa fa il dispositivo

Sul lato frontale si trovano tre pulsanti. Una pressione breve accende il carico per un tempo memorizzato:

Pulsante | Etichetta | Tempo predefinito | impostabile
S1 | Down / Manual (T1) | 5 secondi | 1–600 s via Wi-Fi
S2 | SET (T2) | 10 secondi | 1–600 s via Wi-Fi
S3 | UP (T3) | 15 secondi | 1–600 s via Wi-Fi

Un piccolo display OLED dietro la finestrella mostra in alto la ricezione Wi-Fi, l'ora in grande (impostata tramite un server orario Internet) e lo stato Idle; in basso la data e la memoria libera. Quando un timer è in corso, al centro appare il conto alla rovescia in secondi e a destra Feed.

L'uso avviene senza app e senza cloud tramite una piccola pagina web ottimizzata per smartphone, fornita dall'ESP32 stesso (nel browser http://feeder-relais.local ): avviare i timer, impostare i tempi, consultare i valori di rete e di stato. Per l'integrazione in un sistema di domotica (per esempio ioBroker o Home Assistant) è inoltre disponibile una snella interfaccia JSON (capitolo 11).

## 1.2 La catena di segnale

Dalla pressione del pulsante al carico commutato, il segnale attraversa cinque stazioni. Ciascuna ha esattamente un compito:

Tasto ─► ESP32-C3 ─► 330 Ω ─► PhotoMOS ─► Shelly 1PM ─► Carico
S1–S3 | misura il | limita | isola | commuta e | (pompa,
| tempo, | corrente | galvanica- | misura la | motore
| pilota | del LED | mente | potenza | mangime,
| l'OLED | | | 230 V | luce …)

ℹ Perché tante stazioni?
L'ESP32 lavora con i 3,3 volt innocui. Non deve mai «toccare» direttamente i 230 volt. Il PhotoMOS è il ponte: separa completamente bassa tensione e tensione di rete tramite la luce (dettagli nel capitolo 3). Lo Shelly si occupa della vera e propria commutazione del carico e ne misura anche la potenza.

## 1.3 Cosa cambia nella versione 3

Questo manuale descrive la versione 3 della scheda. Rispetto alla prima versione, la struttura si è notevolmente semplificata:

Lo Shelly si trova fuori dalla scheda ed è collegato tramite un morsetto (capitolo 13). Questo mantiene la scheda piccola e la tensione di rete ben delimitata.
Tutta l'elettronica si trova sul retro della scheda. Sul lato anteriore restano solo i tre pulsanti e il connettore del display — cioè tutto ciò che viene azionato o visto attraverso il pannello frontale.
La scheda è a quattro strati con piani di massa continui. Questo la rende poco soggetta a interferenze e permette una separazione pulita tra tensione di rete e bassa tensione (capitolo 6).
La parte posteriore dell'involucro viene stampata in 3D (capitolo 5) ed è abbastanza profonda da accogliere scheda e Shelly.

•

•

•

•

# 2 Sicurezza — leggere per prima cosa

Pericolo di morte per i 230 volt
La tensione di rete può essere letale. Chi realizza, collauda e mette in servizio il lato a 230 V deve conoscere i rischi e padroneggiare le regole dell'elettrotecnica. In caso di dubbio: rivolgersi a un elettricista qualificato. Non esiste eccezione o fretta che lo giustifichi.

## 2.1 Le regole fondamentali

Tutti i primi test funzionali di ESP, pulsanti e OLED avvengono esclusivamente via USB — senza alcuna tensione di rete collegata.
Il primo test a 230 V avviene dietro un interruttore differenziale (RCD/PRCD, «presa salvavita»), con l'involucro chiuso. Non intervenire mai sul dispositivo aperto e sotto tensione.
Davanti all'alimentatore vanno posti un fusibile (1 A ritardato) e un varistore. I piccoli moduli AC/DC non li includono di per sé.
Sulla scheda, tra ogni conduttore a 230 V e la bassa tensione vale almeno 6 mm di distanza (distanza di dispersione). Il perché è spiegato nella sezione 2.2.
Per il relè PhotoMOS è obbligatorio usare un tipo con tensione di tenuta ≥ 400 V (capitolo 3). Un normale optoisolatore non è ammesso.

•

•

•

•

•

## 2.2 Perché 6 millimetri di distanza

Tra due superfici di rame su una scheda, la corrente non può solo scoccare attraverso l'aria, ma anche strisciare lungo la superficie — favorita da polvere, umidità e sporco. Questa «distanza di dispersione» deve essere sufficientemente grande a 230 volt. La fissiamo a 6 mm; un valore generoso, con margine di riserva. L'unica eccezione ammessa è l'interno del relè PhotoMOS stesso — questo componente è il punto di isolamento certificato e può portare tensione di rete e bassa tensione a pochi millimetri di distanza (capitolo 6).

⚠ La regola dei 6 mm non è un consiglio
È definita nel progetto della scheda come regola di verifica fissa (capitoli 6 e 8). Chi modifica la scheda non deve allentare questa regola — è il motivo per cui il dispositivo resta sicuro nell'uso quotidiano.

## 2.3 Il percorso sicuro verso la prima messa in servizio

L'ordine di questo manuale è scelto deliberatamente in modo che tu faccia tutto ciò che è pericoloso per ultimo e possa esercitarti senza rischi fino ad allora:

Montare i componenti sulla scheda e flashare l'ESP senza alimentatore via USB (capitoli 9 e 10).

1

Test solo USB: pulsanti, OLED e l'uscita PhotoMOS vengono verificati completamente senza tensione di rete (capitolo 14).

2

Solo quando tutto funziona si aggiungono alimentatore e Shelly — e il primo test con tensione di rete avviene dietro un RCD con l'involucro chiuso (capitolo 14).

3

# 3 Come funziona il sistema

## 3.1 I componenti e i loro compiti

Componente | Compito
ESP32-C3 Super Mini | Il «cervello». Un piccolo microcontrollore con Wi-Fi. Legge i pulsanti, misura il tempo, disegna l'OLED, fornisce la pagina web e pilota il PhotoMOS. Alimentato a 5 V, lavora internamente a 3,3 V.
Relè PhotoMOS | Il punto di isolamento galvanico tra 3,3 V e 230 V. Dettagli nella sezione 3.3.
Resistenza di limitazione 330 Ω | Limita la corrente attraverso il LED interno del PhotoMOS, in modo che non venga sovraccaricato.
Alimentatore (modulo AC/DC) | Ricava dai 230 V~ i 5 V con cui funziona l'ESP. Un modulo già pronto e incapsulato.
Shelly 1PM Mini Gen4 | Commuta il carico vero e proprio, ne misura la potenza ed è inoltre raggiungibile via Wi-Fi. Si trova fuori dalla scheda.
Display OLED 0,91" | Mostra orologio, conto alla rovescia e stato. Viene solo innestato, non saldato.
Fusibile + varistore | Proteggono dal sovraccarico e dalla sovratensione sul lato di rete.

## 3.2 Perché uno Shelly — e perché fuori dalla scheda

Lo Shelly 1PM Mini Gen4 è un relè di commutazione già pronto e collaudato, con misura della potenza. Usarlo comporta tre vantaggi: la commutazione rischiosa del carico è affidata a un prodotto finito certificato; la potenza viene misurata (si vede se il carico sta effettivamente funzionando); e lo Shelly stesso è raggiungibile via Wi-Fi, qualora lo si voglia integrare ulteriormente.

La nostra scheda «preme» l'interruttore per lo Shelly solo come un vero segnale hardware, senza dipendenza dal Wi-Fi per la funzione principale. Nella versione 3 lo Shelly si trova fuori dalla scheda ed è collegato tramite un morsetto (capitolo 13). Questo mantiene la scheda piccola, i percorsi a 230 V corti e la struttura ordinata.

ℹ «Switch / Follow»
Lo Shelly viene impostato in modo che il suo relè resti acceso esattamente per tutto il tempo in cui è presente il nostro segnale (modalità Switch ovvero Follow). L'intera temporizzazione resta così all'ESP — lo Shelly si limita a seguire.

## 3.3 Cos'è un PhotoMOS e perché proprio questo

Un PhotoMOS è un minuscolo relè a semiconduttore. Da un lato si trova un LED, pilotato dall'ESP a 3,3 V. Dall'altro lato un interruttore comandato dalla luce, che può commutare la tensione di rete. Tra i due c'è solo luce — quindi un isolamento galvanico completo tra bassa tensione e 230 V.

L'ingresso di commutazione dello Shelly è riferito alla tensione di rete (si aspetta una fase commutata). Per questo il PhotoMOS deve sopportare una tensione di tenuta ≥ 400 V — per esempio un Omron G3VM-601BY o un Panasonic AQY216.

Niente PC817 & co.
Un normale optoisolatore (per esempio il PC817) non è ammesso per il lato di rete — non tiene la tensione in modo sicuro e non è costruito per l'isolamento dalla tensione di rete. Usare solo un PhotoMOS adatto alla tensione di rete con ≥ 400 V.

## 3.4 Ogni componente nel dettaglio

Ecco la funzione esatta di ogni componente — con i valori effettivamente montati sulla scheda v3. Le sigle (riferimenti) sono quelle riportate sulla serigrafia della scheda.

Sigla | Valore | Funzione esatta
U1 | ESP32-C3 Super Mini | Il microcontrollore con Wi-Fi. Funziona a 5 V, genera internamente 3,3 V tramite un regolatore (anche per l'OLED). Porta un LED RGB integrato (WS2812) su GPIO8. Pilota pulsanti, OLED, PhotoMOS e l'interfaccia web.
K1 | G3VM-601AY2 | Il PhotoMOS — l'isolamento galvanico tra 3,3 V e 230 V. Pin 1/2 = LED interno (pin 1 tramite R1 da GPIO6, pin 2 a GND), pin 3/4 = interruttore comandato dalla luce (pin 3 = L_F, pin 4 = SW_SHELLY). Tensione di tenuta ≥ 400 V.
R1 | 330 Ω | Resistenza di limitazione del LED di K1. Da ~3,3 V meno ~1,2 V di tensione diretta del LED scorrono circa 6 mA — sufficienti per una commutazione sicura, ben al di sotto del valore limite del LED.
PS1 | TSP-05 (5 V / 3 W) | L'alimentatore: ricava dai 230 V~ (L_F + N) i 5 V/GND per l'ESP. 3 W = 600 mA — sufficienti per i picchi di trasmissione Wi-Fi (~350 mA) più l'OLED.
C1 | 220 µF / 10 V | Condensatore di supporto su +5 V: attutisce brevi picchi di corrente durante la trasmissione Wi-Fi ed evita il calo di tensione che altrimenti farebbe riavviare l'ESP.
C2 | 100 nF | Condensatore di disaccoppiamento direttamente su +5 V/GND: assorbe i disturbi ad alta frequenza vicino al chip.
F1 | 1 A ritardato | Fusibile (5×20 mm) in serie: X1 (L_IN) → F1 → L_F. Protegge in caso di corto circuito/sovracorrente. «Ritardato» affinché la corrente di spunto dell'alimentatore non lo faccia scattare erroneamente.
RV1 | S14K275 (varistore) | Protezione da sovratensione in parallelo tra L_F e N: limita i picchi di tensione (transitori di commutazione, disturbi di rete) e protegge alimentatore ed elettronica.
J2 | OLED SSD1306 128×32 | Il display. Indirizzo I²C 0x3C, 400 kHz. Viene solo innestato (assegnazione GND/VCC/SCL/SDA).

SW1–

3 | Pulsante 6×6 mm | I tre micropulsanti T1/T2/T3. Un contatto a GND, l'altro a GPIO3/4/5 — l'ESP usa i pull-up interni, una pressione porta il pin a GND.

E i morsetti di collegamento sul bordo della scheda:

Sigla | Collegamento | Assegnazione
X1 | Ingresso rete | 1 = N, 2 = L_IN (230 V in ingresso)

X2 | Uscita carico | 1 = O (commutato), 2 = N
X3 | Snubber | 1 = O, 2 = N — per una rete RC opzionale su carichi induttivi
J1 | Shelly | 1 = SW, 2 = O, 3 = L, 4 = N (verso lo Shelly esterno, capitolo 13)

# 4 Lista della spesa: materiali e utensili

Tutto ciò che serve per un Feeder-Relais. La scheda stessa la fai produrre (capitolo 7); i componenti si ordinano e si saldano (capitolo 9).

## 4.1 Componenti sulla scheda

Sigla | Componente | Valore / tipo | Nota
U1 | ESP32-C3 Super Mini | 18 × 24 mm, USB-C | Controller con Wi-Fi
K1 | Relè PhotoMOS | Omron G3VM-601AY2 (o -601BY / Panasonic AQY216)

≥ 400 V!

PS1 Modulo alimentatore
AC/DC
5 V / 3 W (classe HLK-PM05) | verificare la distanza dei pin
— | Display OLED | 0,91" SSD1306, 128 × 32, I²C | Pin: GND VCC SCL SDA, indirizzo 0x3C

SW1–

3 | Micropulsante | 6 × 6 mm, corsa 1,5 mm | posizione fissa (pannello frontale)
R1 | Resistenza | 330 Ω | resistenza di limitazione LED PhotoMOS
F1 | Fusibile + portafusibile | 1 A ritardato, 5 × 20 mm | lato primario, obbligatorio
RV1 | Varistore | S14K275 | lato primario, obbligatorio
C1 / C2 | Condensatori | 220 µF/10 V & 100 nF | buffer 5 V e disaccoppiamento
X1 | Ingresso rete | 2 poli (L, N) | morsetto a vite, 230 V in ingresso
X2 | Uscita carico | 2 poli (O, N) | verso il carico commutato
X3 | Snubber | 2 poli (O, N) | rete RC opzionale per carichi induttivi
J1 | Collegamento Shelly | 4 poli (SW, O, L, N) | fili corti verso lo Shelly esterno, capitolo 13
J2 | Zoccolo OLED | 1 × 4, passo 2,54 | GND/VCC/SCL/SDA, il display viene innestato

## 4.2 Gruppi esterni alla scheda

Shelly 1PM Mini Gen4 (tipo S4SW-001P8EU), max. 8 A / 240 V, dimensioni circa 29 × 34 × 16 mm.
Materiale di montaggio: nastro biadesivo VHB o una clip stampata in 3D, per fissare Shelly e alimentatore nell'involucro.
Fili corti (per es. 0,75 mm²) per il collegamento scheda ↔ Shelly e verso l'uscita del carico.

## 4.3 Utensili

Saldatore (a temperatura regolabile), stagno, treccia dissaldante, flussante.
Pinzetta fine, tronchesine, spellafili.
Un cavo dati USB-C (attenzione: molti cavi economici possono solo caricare!) e un PC. Multimetro (prova di continuità e di tensione).
Una stampante 3D per la parte posteriore dell'involucro (oppure un servizio di stampa). Per il test a 230 V: un RCD/PRCD.

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
# 5 L'involucro

L'involucro è composto da due parti: la parte anteriore (il pannello frontale originale con la finestrella e i tre pulsanti a stantuffo) e la parte posteriore, che stampi tu stesso in 3D. La scheda viene avvitata da dietro a sei colonnette, il display si trova dietro la finestrella.


La parte posteriore stampata in 3D con le sei colonnette filettate e la linguetta di sospensione (in alto).

## 5.1 Struttura: parte anteriore e posteriore

La parte anteriore è la parte superiore dell'involucro originale. Porta la finestrella (dietro cui si trova l'OLED) e gli stantuffi che, premuti, azionano i tre pulsanti sulla scheda. Per questo la posizione dei pulsanti non è negoziabile — devono trovarsi esattamente sotto gli stantuffi (capitolo 9).


La parte anteriore (originale) con finestrella e i tre stantuffi dei pulsanti.

Nella versione 3 la parte posteriore è deliberatamente più profonda dell'originale (35 mm invece dei 5,7 mm originari), affinché scheda e Shelly esterno ci stiano comodamente. Sul bordo superiore si trova una linguetta di sospensione con foro a serratura per il montaggio a parete.

## 5.2 Stampare la parte posteriore

Il modello si trova come file OpenSCAD nel progetto, in box/feeder_back.scad . OpenSCAD è un programma gratuito che genera un modello 3D a partire da un file di testo — il vantaggio: tutte le misure sono definite come variabili in cima al file e possono essere adattate.

✓ Prima stampa la scheda come sagoma
Nel progetto è disponibile anche box/Timer-Ersatzplatine-v3-BOARD.stl — una riproduzione 1:1 della scheda (contorno, fori di fissaggio, fessure). Stampala piatta e inseriscila nella parte posteriore prima di ordinare la scheda vera. Così verifichi senza rischi che tutto sia compatibile (capitolo 7).

## 5.3 Spazio disponibile in altezza e fissaggio

La scheda viene avvitata da dietro con sei viti alle colonnette della parte posteriore (passo colonnette 45 mm × 70 mm, foro vite 3,2 mm, svasatura per la testa della vite sul retro). Altri quattro punti sul pannello frontale centrano ulteriormente la scheda.

Misura | Valore
Dimensione esterna parte posteriore | 109,8 × 90,8 mm
Profondità parte posteriore (v3) | 35 mm
Spessore pareti e fondo | 1,3 mm
Dimensione scheda | 101,6 × 77,5 mm
Passo colonnette | 45 mm (X) × 70 mm (Y)

⚠ Niente deve sporgere verso il basso (verso il fronte)
Tra scheda e pannello frontale lo spazio è ridotto. Tutti i componenti alti si trovano perciò sul retro della scheda (capitolo 6). Sul lato anteriore restano solo i pulsanti piatti e il connettore del display.

1 Aprire OpenSCAD e caricare box/feeder_back.scad .

Con F6 calcolare il modello e salvarlo come file stampabile tramite File → Esporta → STL. È già disponibile un STL pronto: box/feeder_back_35mm.stl .

2

Caricare l'STL nello slicer della propria stampante. Consiglio: stampare con il lato aperto verso l'alto, 3–4 linee di parete, riempimento 20–30 %, nessun supporto necessario.

3

# 6 Capire la scheda

Non devi progettare la scheda da solo — è già pronta nel progetto, in kicad-v3/ . Questo capitolo spiega come è strutturata, in modo che tu sappia cosa va dove durante il montaggio e il collaudo. Chi vuole modificarla trova la guida a KiCad nel capitolo 8.

## 6.1 Lato anteriore e posteriore

Nella versione 3 tutta l'elettronica si trova sul retro. Sul lato anteriore (verso il pannello frontale) restano solo i tre pulsanti e lo zoccolo OLED — tutto ciò che viene azionato o visto.

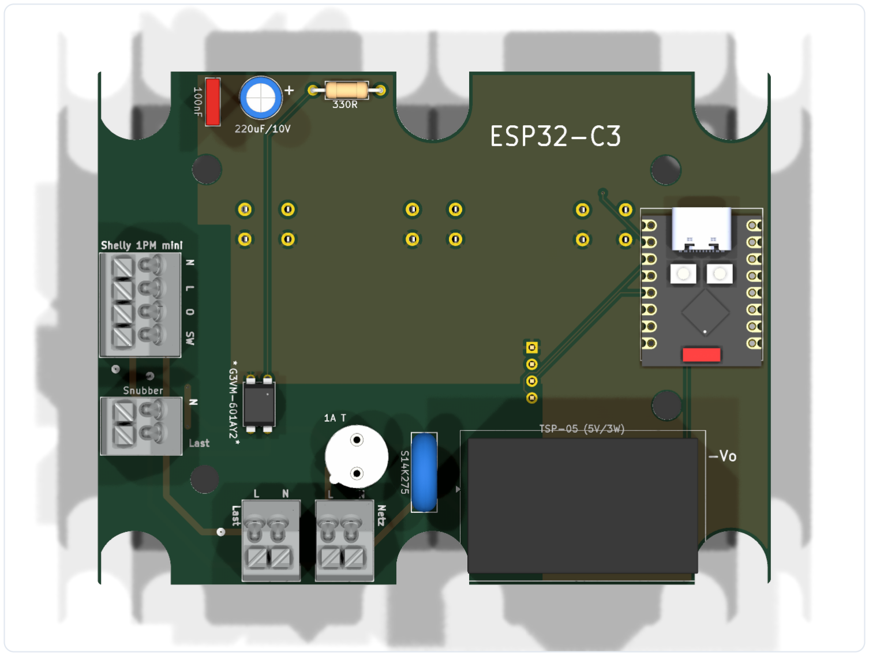
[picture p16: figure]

Il retro porta ESP, alimentatore, PhotoMOS e i morsetti a 230 V. Tensione di rete (in basso) e bassa tensione (in alto) sono spazialmente ben separate.

## 6.2 Quattro strati e i piani di massa

La scheda ha quattro strati di rame: i due strati esterni (lato anteriore e posteriore) portano le piste, i due strati interni sono piani di massa continui nella zona a bassa tensione. Tali piani di massa agiscono come un piano di riferimento stabile: rendono la struttura poco soggetta a interferenze e la funzione Wi-Fi stabile.

ℹ Importante per la sicurezza
Nella zona a tensione di rete non c'è alcun rame interno. I conduttori a 230 V corrono esclusivamente sui due strati esterni, e i piani di massa mantengono ovunque almeno
6 mm di distanza dalla tensione di rete. Così non può crearsi da nessuna parte, all'interno della scheda, una vicinanza pericolosa.

## 6.3 Tensione di rete solo all'esterno: la regola dei 6 millimetri

Le cinque reti L_IN , L_F , N , SW_SHELLY e O_LAST portano 230 volt. Sono raggruppate in una classe di rete «230V» propria (piste più larghe, distanze maggiori) e si trovano tutte in basso a sinistra, lontano dall'elettronica. Una regola di verifica definita nel progetto richiede 6 mm di distanza tra ogni rete a 230 V e ogni bassa tensione.

La sola eccezione è il relè PhotoMOS K1: il suo involucro è il punto di isolamento certificato (pin 1/2 = bassa tensione, pin 3/4 = tensione di rete). Solo lì i due mondi possono incontrarsi a pochi millimetri di distanza — esattamente per questo il componente è costruito.

## 6.4 Le reti e l'assegnazione dei pin

Quale conduttore porta cosa lo mostra la seguente panoramica:

Nome rete | porta | collega
L_IN | 230 V (non protetta) | Ingresso rete X1 → fusibile F1
L_F | 230 V (protetta) | F1 → varistore RV1, alimentatore PS1, PhotoMOS K1.3, Shelly J1.L
N | 230 V neutro | X1 → RV1, PS1, Shelly J1.N, carico X2, snubber X3
SW_SHELLY | 230 V commutata | PhotoMOS K1.4 → Shelly J1.SW
O_LAST | 230 V commutata | Shelly J1.O → uscita carico X2 + snubber X3
+5V | bassa tensione | Alimentatore → ESP 5V, C1, C2
GND | bassa tensione | Massa: ESP, pulsanti, PhotoMOS, OLED
+3V3 | bassa tensione | Uscita ESP-3V3 → OLED

L'ESP32-C3 utilizza questi pin:

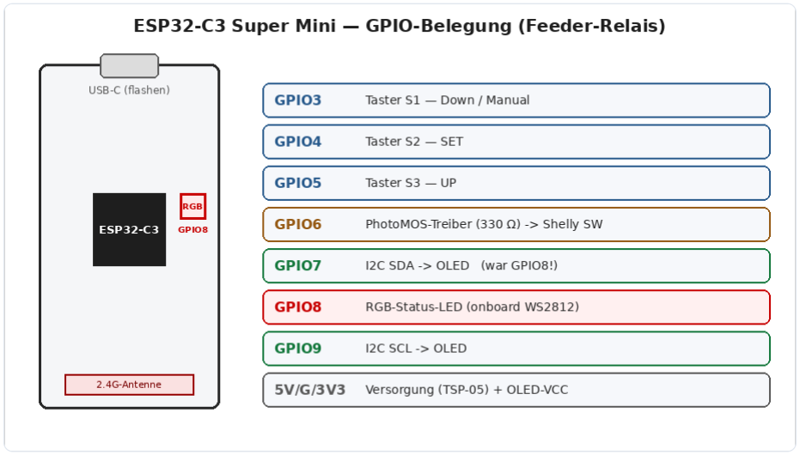
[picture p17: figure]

I collegamenti utilizzati dell'ESP32-C3 Super Mini.

Pin | Funzione

5V / G | alimentazione dall'alimentatore
3V3 | alimenta l'OLED
GPIO3 / 4 / 5 | pulsanti T1 / T2 / T3
GPIO6 | pilotaggio PhotoMOS (tramite 330 Ω)
GPIO7 | I²C-SDA (OLED)
GPIO8 | LED RGB integrato (stato)
GPIO9 | I²C-SCL (OLED)

ℹ Perché SDA su GPIO7 invece che su GPIO8?
Su GPIO8 si trova il piccolo LED RGB di stato del modulo ESP. Se lì ci fosse l'I²C, il traffico dati pilotarebbe il LED in modo incontrollato. Per questo SDA si trova su GPIO7. Lo stesso LED RGB mostrerà in seguito il semaforo di stato del dispositivo (capitolo 11).

## 6.5 Ogni collegamento dell'ESP nel dettaglio

Questa tabella è la corrispondenza vincolante tra scheda e firmware. A sinistra è indicato cosa fa il firmware ( timer-relais-c3.yaml ) con il pin — con la sua configurazione esatta; a destra, dove lo porta la scheda. I due lati devono corrispondere esattamente, altrimenti il dispositivo non funziona.

Pin ESP | Firmware (ID e configurazione) | Scheda | Funzione nel dettaglio
| invertito, 30 ms di | GND | Pulsante S1 (Down/Manual). Livello di riposo HIGH; la pressione porta a GND (LOW) → considerato «premuto». Breve = avviare Timer 1.
GPIO3 | btn_s1 | · ingresso,
pull-up interno,

debounce

Pad 3 → | /BTN1 | →
pulsante S1 verso
GPIO4 | btn_s2 | · ingresso,
pull-up, invertito,
30 ms
Pad 4 → | /BTN2 | →
pulsante S2 verso
GND

Pulsante S2 (SET). Breve = Timer 2; lunga ≥ 3 s = menu informazioni.

GPIO5 | btn_s3 | · ingresso,
pull-up, invertito,
30 ms
Pad 5 → | /BTN3 | →
pulsante S3 verso
GND

Pulsante S3 (UP). Breve = Timer 3; lunga ≥ 1,2 s = arresta tutto.

GPIO6 | shelly_trigger | ·
uscita GPIO
Pad 6 → | /PMOS_DRV | →
R1 330 Ω → anodo LED
K1

Pilota il PhotoMOS. HIGH = LED acceso = PhotoMOS conduce = Shelly-SW riceve L → carico acceso. LOW = spento.

GPIO7 | i2c: sda | · 400 kHz | Pad 7 → | /SDA | →
OLED J2.4

Linea dati I²C verso l'OLED. Si trova intenzionalmente su GPIO7 (non GPIO8).

GPIO8 | status_led | · WS2812
(GRB), attenuato

interno al modulo —
nessuna rete sulla
scheda (Pad 8 libero)

LED RGB di stato integrato (semaforo verde/giallo/rosso). Si trova fisso su GPIO8 del modulo; per questo qui non deve trovarsi un secondo segnale — il motivo per cui SDA è passato a GPIO7.

GPIO9 | i2c: scl | · 400 kHz | Pad 9 → | /SCL | →
OLED J2.3

Linea di clock I²C verso l'OLED (indirizzo 0x3C).

5V /
GND

Alimentazione del
| modulo
/+5V | / | GND
dall'alimentatore

5 V dal modulo AC/DC; GND è la massa comune (anche gli strati interni).

3V3 | Uscita del regolatore
| integrato
/+3V3 | → OLED-VCC | L'ESP genera internamente 3,3 V e con
essi alimenta l'OLED.

⚠ Proprio questa corrispondenza è decisiva
Se sulla scheda SDA viene collegato per errore a GPIO8 (dove si trova il WS2812), l'OLED resta nero e il segnale del LED disturba la linea dati. Nell'autocostruzione verificare quindi: OLED-SDA deve essere collegato al pad 7 dell'ESP (GPIO7), SCL al pad 9 (GPIO9) — GPIO8 resta libero.

# 7 Far produrre la scheda

Una scheda a quattro strati non si costruisce in casa — la si fa produrre da un produttore di circuiti stampati. Oggi è economico e semplice: si caricano alcuni file e si ricevono le schede finite per posta.

## 7.1 Prima una prova in plastica

✓ Il trucco della prova d'accoppiamento fa risparmiare
Prima di ordinare le schede, stampa in 3D il file allegato box/Timer-Ersatzplatine-v3-BOARD.stl 1:1 (piatto, senza supporti) e inseriscilo nella parte posteriore stampata. Il contorno combacia, le sei fessure si allineano con le colonnette, i fori delle viti sono nella posizione giusta? Questi cinque minuti ti risparmiano un ordine sbagliato e costoso.

In alternativa (o in aggiunta) stampa il contorno della scheda su carta in scala 1:1 e ritaglialo.

## 7.2 Generare i dati Gerber

«Gerber» è il formato di file standard nel quale i produttori si aspettano le schede — un file per ogni strato, più i dati di foratura. I Gerber già pronti si trovano già nel progetto; puoi generarli da KiCad così:

1 Aprire in KiCad il progetto kicad-v3/Timer-Ersatzplatine-v3.kicad_pcb .

File → Fabrication Outputs → Gerber Files — selezionare tutti gli strati standard, esportare.

2

3 Nella stessa finestra generare i file di foratura (Excellon).

4 Comprimere tutti i file generati in un archivio ZIP.

## 7.3 Ordinare presso un produttore

Carica lo ZIP presso un fornitore come JLCPCB, PCBWay o Aisler. Impostazioni importanti:

Impostazione | Valore
Strati | 4
Spessore materiale | 1,6 mm (standard)
Finitura superficiale | HASL senza piombo o ENIG
Rame | 1 oz (35 µm)
Colore | indifferente

⚠ Impostare quattro strati
Scegli davvero 4 strati. Un'autocostruzione a due strati non avrebbe piani di massa interni — l'immunità Wi-Fi e ai disturbi sarebbe peggiore, e le regole di verifica del progetto non sarebbero più valide.

# 8 KiCad passo dopo passo (solo per modifiche personali)

Questo capitolo serve solo se vuoi modificare tu stesso la scheda. Per la sola autocostruzione puoi saltarlo — i dati di produzione già pronti sono inclusi. KiCad è un programma gratuito per la progettazione di schede (testato con KiCad 8/9/10; i nomi dei menu possono variare leggermente).

## 8.1 Aprire il progetto e verificare lo schema elettrico

## 8.2 Footprint e classi di rete

Ogni simbolo di componente è collegato a un footprint — l'immagine di saldatura sulla scheda. Verifica in Strumenti → Assegna footprint che, per esempio, PS1 corrisponda all'alimentatore effettivamente acquistato (misurare la distanza dei pin!) e che il PhotoMOS corrisponda alla forma costruttiva SMD o DIP.

Le classi di rete sono definite nel file di progetto e non devono essere modificate: Default (0,2 mm di distanza e larghezza pista) e 230V (1,0 mm di distanza e larghezza pista) con le cinque reti L_IN, L_F, N, SW_SHELLY, O_LAST.

1 Avviare KiCad e aprire kicad-v3/Timer-Ersatzplatine-v3.kicad_pro .

2 Avviare l'editor dello schema elettrico. Mostra come sono collegati tutti i componenti.

Eseguire Strumenti → Verifica regole elettriche (ERC). Gli avvisi relativi a «pin di alimentazione non collegati» sono noti e non critici.

3

## 8.3 La regola dei 6 millimetri e il DRC

La regola sulla distanza di dispersione si trova come file separato | Timer-Ersatzplatine-
v3.kicad_dru | nel progetto. Richiede 6 mm tra 230 V e bassa tensione — con la deliberata
eccezione del PhotoMOS K1:

(version 1)
(rule "230V->SELV 6mm (K1-Barriere ausgenommen)" (condition "... 230-V-Netz gegen Nicht-230-V-Netz, K1 ausgenommen ...")
(constraint creepage (min 6mm))
(constraint clearance (min 6mm)))

Dopo ogni modifica, eseguire il DRC (Design Rules Check, Verifica → Verifica regole di progettazione) finché non risulta privo di errori.

⚠ Piani di massa arretrati di 6 mm
Il riempimento automatico dei piani di massa rispetta solo la distanza della classe di rete, non la regola dei 6 mm. Per questo i piani di massa sono sagomati geometricamente in modo da restare ovunque a 6 mm dalla tensione di rete. Chi ridisegna i piani deve mantenere questa distanza a mano.

## 8.4 Dati di produzione

Se DRC e controllo visivo (vista 3D con Alt+3 ) sono corretti, esporta i dati Gerber e di foratura come descritto nel capitolo 7.

# 9 Montare i componenti sulla scheda

«Montare» significa: saldare i componenti sulla scheda. Si procede dai componenti piatti a quelli alti — così la scheda resta sempre stabile durante la saldatura.

## 9.1 Ordine di montaggio e utensili

Ordine consigliato: R1 → C2 → PhotoMOS → pulsanti → zoccolo OLED J4 → C1 → portafusibile F1 → varistore RV1 → morsetti. L'ESP si monta solo dopo essere stato flashato e testato (capitoli 10 e 14).

## 9.2 I componenti SMD

Il PhotoMOS è (a seconda del tipo) un piccolo componente SMD. Ecco come saldarlo correttamente:

ℹ Orientamento del PhotoMOS
Il pin 1 è contrassegnato (punto o angolo smussato). Il lato a bassa tensione (pin 1/2) è rivolto verso l'elettronica, il lato a tensione di rete (pin 3/4) verso l'angolo a 230 V. È l'impronta di saldatura a indicare la direzione — non tirare a indovinare, seguire la serigrafia.

1 Stagnare leggermente un pad.

Posizionare il componente con la pinzetta e saldarlo al pad stagnato — controllare l'orientamento.

2

3 Saldare i pin rimanenti. Il flussante aiuta; i ponti di stagno si evitano usando poco stagno.

## 9.3 I componenti a foro passante e i connettori

Pulsanti SW1–3: posizionarli con precisione — dovranno trovarsi esattamente sotto gli stantuffi del pannello frontale. Premerli a filo sulla scheda, poi saldare.
Zoccolo OLED J4: saldare la barra di pin femmina (1×4) in modo che stia perpendicolare. L'OLED viene poi solo innestato, non saldato.
Fusibile, varistore, morsetti: nell'angolo a 230 V, con distanza dall'elettronica. Saldare accuratamente, senza saldature fredde.

ℹ L'OLED si innesta, non si salda
All'OLED saldi una barra di pin (rivolta all'indietro) che si inserisce nello zoccolo J4. Il display si trova poi con un sottile cuscinetto in schiuma direttamente contro la finestrella. Resta così sostituibile e l'altezza d'ingombro è ridotta.

•

•

•

# 10 Caricare il firmware

Il «firmware» è il programma che gira sull'ESP. La prima volta viene caricato sul chip via cavo USB. Tutti gli aggiornamenti successivi avvengono poi via etere (capitolo 15).

## 10.1 Cosa serve

l'ESP32-C3 Super Mini (non ancora saldato),
un cavo dati USB-C — molti cavi economici possono solo caricare; con questi il chip non viene riconosciuto,
un PC con Google Chrome o Microsoft Edge (metodo B) — oppure ESPHome sul PC (metodo A).


Collegare l'ESP32-C3 al PC tramite USB-C.

ℹ Non devi compilare nulla
Le immagini già pronte si trovano nel progetto, in | firmware/build/ : | feeder-
relais.factory.bin | per il primo flashing e | feeder-relais.ota.bin | per i successivi
aggiornamenti via web. Non contengono alcuna credenziale Wi-Fi — la configuri dopo il flashing (capitolo 11).

•
•

•

## 10.2 Metodo A — con ESPHome

ESPHome è lo strumento con cui il firmware viene compilato e caricato. Un file secrets.yaml non è necessario — non vengono compilati dati Wi-Fi.

✓ Linux: «Permission denied»?
Se l'accesso a | /dev/ttyACM0 | viene negato, aggiungi il tuo utente al gruppo | dialout | e
accedi di nuovo:

sudo usermod -aG dialout $USER

1 Collegare l'ESP via USB-C.

Eseguire nella cartella del progetto:

esphome run firmware/timer-relais-c3.yaml

2

ESPHome compila, chiede la porta seriale (su Linux per es. | /dev/ttyACM0 , su Windows
una | COMx ) e flasha.

3

4 Dopo il riavvio l'ESP apre il suo hotspot di configurazione → si prosegue con il capitolo 11.

## 10.3 Metodo B — nel browser

Per il file già pronto | feeder-relais.factory.bin | senza alcuna installazione:


La procedura di flashing nel browser tramite il web flasher.

1 | In Chrome/Edge aprire la pagina | https://espressif.github.io/esptool-js/ .

2 Collegare l'ESP tramite cavo dati USB-C.

3 | Lasciare il baud rate a | 115200 , cliccare su Connect e scegliere la porta seriale dell'ESP.
In Flash Address inserire | 0 , con Choose File scegliere | feeder-relais.factory.bin ,
quindi Program. Attendere finché non appare «Hard resetting…».

4

5 Proseguire con il capitolo 11.

## 10.4 Se il flashing si blocca

Sintomo | Causa / soluzione
L'ESP non viene riconosciuto | cavo di ricarica invece di cavo dati → provare un altro cavo USB-C, un'altra porta

Nessuna porta nel
browser

usare Chrome/Edge; su Windows eventualmente i driver (CH340/CP210x)

«Connect» fallisce | Modalità boot: tenere premuto BOOT + toccare RESET + rilasciare BOOT,
quindi riconnettersi
Nessun | ….local | dopo | configurare prima il Wi-Fi (capitolo 11); mDNS richiede un momento

# 11 Configurare il Wi-Fi e usare il browser

## 11.1 L'hotspot di configurazione

Il firmware non porta deliberatamente alcuna credenziale Wi-Fi. Dopo il flashing l'ESP apre un proprio hotspot:

ℹ Si configura una volta, poi mai più
I dati Wi-Fi sono memorizzati sotto una chiave di memoria fissa e sopravvivono agli aggiornamenti del firmware. Per un reset di fabbrica, flasha l'immagine factory con «Erase all flash».

Sul telefono/PC collegarsi alla rete Wi-Fi «Feeder-Relais Setup» (password feeder1234 ).

1

2 | Si apre una finestra di accesso (in alternativa richiamare | http://192.168.4.1 ).

Selezionare la propria rete Wi-Fi domestica, inserire la password, salvare — l'ESP si
| riavvia e si connette.

3

4 | Da questo momento è raggiungibile su | http://feeder-relais.local .

## 11.2 L'interfaccia web

http://feeder-relais.local apre un'app web mobile con cinque schede:

Start: tre grandi pulsanti (avviano T1/T2/T3), conto alla rovescia in tempo reale e Stop. Tempi: in alto la selezione della lingua (Deutsch/English/Français), sotto i tre tempi dei timer (1–600 s), salvati in modo permanente.
Rete: Wi-Fi, modalità IP DHCP/statica, server NTP, hostname, roaming Wi-Fi, riavvio (capitolo 12).
Stato: versione, tempo di funzionamento, memoria libera, Wi-Fi con barra del segnale, IP/ MAC, motivo del reset, stato del relè.
Servizio: log in tempo reale, aggiornamento del firmware e riavvio (capitolo 15).

## 11.3 Il semaforo di stato e l'interfaccia JSON

Nell'intestazione si trova un punto di stato: verde = tutto in ordine, giallo = un timer è in corso, rosso = anomalia a riposo (per es. OLED non raggiungibile o nessun Wi-Fi). Lo stesso semaforo è mostrato sul dispositivo dal LED RGB integrato attenuato.

Per la domotica l'ESP offre un'interfaccia JSON. Gli endpoint principali:

Chiamata | Effetto
GET /api/status | tutti i valori come JSON (attivo, tempo residuo, relè, tempi, Wi-Fi …)
POST /api/trigger?button=N | avvia il pulsante N (1–3) con il suo tempo
POST /api/trigger?seconds=N | commuta ad hoc per N secondi
POST /api/trigger? seconds=N&src=adapter | come sopra, marca l'origine — appare come trg (button/api/ adapter) nello stato e nel log
POST /api/stop | spegne immediatamente
POST /api/config? time1=A&time2=B&time3=C | imposta i tempi (ciascuno 1–600 s)

ℹ Esempio ioBroker
Impostare il tempo del pulsante 1 a 8 secondi: POST http://feeder-relais.local/api/config?time1=8 .

•
•

•

•

•

# 12 Rete, lingua e display

## 12.1 Impostazioni di rete

Nella scheda Rete imposti:

Modalità IP: DHCP (predefinita) o statica (con IP/gateway/maschera/DNS). L'IP statico viene impostato alla connessione successiva ed è attivo dopo un riavvio.
Server NTP: il server orario da cui viene impostato l'orologio (predefinito de.pool.ntp.org ).
Hostname: il nome nella rete (predefinito feeder-relais ). Viene cambiato a runtime — l'indirizzo ….local è valido immediatamente.

## 12.2 Roaming Wi-Fi

L'interruttore roaming Wi-Fi (802.11k/v) ha senso solo se hai più access point con lo stesso SSID (mesh/UniFi) che supportano questa tecnologia. In tal caso il dispositivo può passare in modo mirato all'access point con il segnale più forte. Predefinito: disattivato. Dopo il cambio, il pulsante «Riconnetti ora» aiuta a renderlo effettivo subito.

## 12.3 Uso dei pulsanti e dell'OLED

Sul dispositivo i pulsanti sono etichettati: S1 = Down/Manual, S2 = SET, S3 = UP.

breve S1 / S2 / S3 → avvia il timer 1 / 2 / 3 con il tempo impostato.
lunga UP (S3) ≥ 1,2 s → arresta tutti i timer, spegne.
lunga SET (S2) ≥ 3 s → apre un menu informazioni (solo visualizzazione: Wi-Fi, IP, ora, sistema). S1/S3 scorrono, SET breve chiude.

L'OLED (128 × 32) mostra in alto la barra del Wi-Fi, l'orologio grande oppure il conto alla rovescia e lo stato (Idle/Feed); in basso la data e la memoria libera. Giorno della settimana, stato e titoli dei menu seguono la lingua impostata. Fino alla prima sincronizzazione dell'ora resta «--:--».

•

•

•

•
•
•

# 13 Collegare lo Shelly esterno

Cablare solo in assenza di tensione
Lo Shelly porta 230 volt. Tutti i lavori di cablaggio si eseguono in assenza di tensione, con la spina staccata o l'interruttore automatico disattivato — e in caso di dubbio tramite un elettricista qualificato.

## 13.1 Cablaggio

Lo Shelly ha quattro morsetti: L, N, SW (ingresso di commutazione) e O (uscita carico). Quattro fili corti lo collegano al morsetto della scheda J1:

Scheda (J1) | → Shelly | Significato
J1.3 (L_F) | L | Fase (protetta)
J1.4 (N) | N | Neutro
J1.1 (SW_SHELLY) | SW | il nostro segnale commutato (dal PhotoMOS)
J1.2 (O_LAST) | O | carico commutato verso l'uscita

Lo Shelly viene fissato in posizione orizzontale nell'involucro (nastro biadesivo VHB o clip). I fili corti e i morsetti a vite ben serrati — non deve sporgere rame da nessuna parte.

## 13.2 Configurare lo Shelly (Input Mode)

Dopo la prima accensione configuri lo Shelly una tantum (tramite la sua app o interfaccia web):

1 Collegare lo Shelly al Wi-Fi (istruzioni dello Shelly).

Impostare Input Mode = Switch (Follow) — così il relè segue esattamente il segnale SW.

2

Fatto: da questo momento è l'ESP, tramite il PhotoMOS, a determinare per quanto tempo funziona il carico.

3

# 14 Assemblaggio e messa in servizio

## 14.1 Montaggio e preparazione dell'ESP

I componenti piccoli sono saldati (capitolo 9). Ora l'ESP:

## 14.2 Il test solo USB

✓ Tutto ciò che conta funziona senza tensione di rete Alimenta l'ESP via USB (nessuna rete!). Verifica:

Una pressione del pulsante avvia il conto alla rovescia sull'OLED.
L'OLED innestato mostra orologio/stato.
L'uscita PhotoMOS commuta: misurare con il multimetro sull'uscita del PhotoMOS (continuità, mentre il timer è in corso).

Solo quando tutto questo è corretto entra in gioco la tensione di rete.

Flashare l'ESP via USB e testare la connessione Wi-Fi (capitoli 10 e 11) — è più comodo prima di saldarlo.

1

2 Saldare l'ESP sulla scheda (barre di pin o direttamente).

•
•
•

## 14.3 Il primo test con tensione di rete

Mai aperto sotto tensione
Il test con tensione di rete avviene solo a involucro chiuso. Per apportare modifiche, togliere sempre prima la tensione.

Controllo visivo: nessun ponte di saldatura, nessun corto circuito tra L/N, ovunque ≥ 6 mm di distanza tra 230 V e bassa tensione.

1

2 Saldare l'alimentatore, collegare lo Shelly (capitolo 13), collegare il carico.

3 Chiudere l'involucro.

4 Accendere tramite un RCD/PRCD. L'OLED mostra orologio/stato.

5 Configurare lo Shelly (Input Mode «Switch»), quindi un test dei pulsanti con il carico.

6 | Impostare i tempi desiderati tramite | http://feeder-relais.local .

# 15 Aggiornamenti del firmware e manutenzione

## 15.1 Aggiornamenti via etere (OTA)

Dopo il primo flashing via USB sono disponibili due percorsi di aggiornamento via etere — la presa USB può tranquillamente essere poco accessibile una volta montato il dispositivo:

OTA di rete: esphome run firmware/timer-relais-c3.yaml aggiorna via Wi-Fi. Caricamento via web: nella scheda Servizio caricare feeder-relais.ota.bin . Il dispositivo si riavvia dopo.

ℹ I dati Wi-Fi restano conservati
Un aggiornamento sovrascrive solo il programma, non le impostazioni memorizzate. Wi-Fi, tempi e configurazione di rete sopravvivono all'aggiornamento.

## 15.2 Il registro di servizio

La scheda Servizio, con la visualizzazione in tempo reale attivata, mostra le ultime righe di log, filtrate per livello (ERROR/WARN/INFO/DEBUG). Questo aiuta nella risoluzione dei problemi senza dover collegare l'ESP a un cavo. I log completi sono disponibili anche tramite esphome logs firmware/timer-relais-c3.yaml .

•
•

# 16 Risoluzione dei problemi

## 16.1 Durante il flashing e la connessione

Problema | Rimedio
L'ESP non viene riconosciuto | cavo dati invece di cavo di ricarica; provare un'altra porta USB
«Connect» fallisce | forzare la modalità boot (tenere premuto BOOT, toccare RESET,
rilasciare BOOT)

feeder-relais.local non
raggiungibile

Wi-Fi configurato nell'hotspot di setup? mDNS richiede un momento; provare direttamente l'indirizzo IP (nel menu OLED)

Manca l'hotspot di setup il dispositivo è già connesso a un Wi-Fi; altrimenti reset di fabbrica (immagine factory con Erase Flash)

## 16.2 Durante il funzionamento

Problema | Rimedio
L'OLED resta scuro | Il display è innestato correttamente su J4? Verificare l'assegnazione GND/VCC/
SCL/SDA

L'orologio mostra
«--:--»

ancora nessun orario dal server NTP; verificare Wi-Fi e server NTP

Punto di stato rosso | OLED non raggiungibile o nessun Wi-Fi — la scheda Stato mostra i dettagli
Il carico non si commuta | Shelly su «Switch/Follow»? Verificare il cablaggio SW/O; misurare l'uscita PhotoMOS nel test solo USB
Il pulsante non si aziona | Il pulsante si trova esattamente sotto lo stantuffo? Verificare i punti di saldatura

17 Appendice: assegnazioni, file,

# glossario

## 17.1 Assegnazione dei pin e elenco delle reti

Pin ESP | Funzione | Rete
5V / G | Alimentazione | +5V / GND
3V3 | Alimentazione OLED | +3V3
GPIO3 / 4 / 5 | Pulsanti T1 / T2 / T3 | BTN1/2/3
GPIO6 | Pilotaggio PhotoMOS (tramite 330 Ω) | PMOS_DRV
GPIO7 | I²C-SDA (OLED) | SDA
GPIO8 | LED RGB di stato integrato | —
GPIO9 | I²C-SCL (OLED) | SCL

Le cinque reti a 230 V (classe di rete «230V»): L_IN , L_F , N , SW_SHELLY , O_LAST .

## 17.2 File del progetto

Percorso | Contenuto
kicad-v3/ | la scheda v3 (KiCad: schema elettrico, layout, regole) + dati di
| produzione
box/feeder_back.scad | parte posteriore dell'involucro (sorgente OpenSCAD) + STL già
| pronto

box/Timer-Ersatzplatine-v3-
BOARD.stl

sagoma della scheda per la prova d'accoppiamento

firmware/timer-relais-c3.yaml | firmware ESPHome
firmware/timer_web.h | app web + interfaccia JSON
firmware/net_config.h | configurazione di rete (IP, NTP, hostname, roaming, lingua)
firmware/build/*.bin | immagini flash già pronte (factory + ota)
README.md | panoramica del progetto (tedesco; traduzioni in docs/ <lingua>/ )
docs/handbuch/…-Handbuch.pdf | questo manuale in PDF (traduzioni in docs/<lingua>/ )

## 17.3 Glossario

Termine | Significato
ESP32-C3 | piccolo microcontrollore con Wi-Fi — il «cervello» del dispositivo
PhotoMOS | relè a semiconduttore che separa bassa tensione e 230 V tramite la luce
Shelly | relè di commutazione Wi-Fi già pronto, con misura della potenza (esterno)
OLED | piccolo display ad alto contrasto
Gerber | formato di file standard per la produzione di schede
Footprint | l'immagine di saldatura di un componente sulla scheda
DRC | Design Rules Check — la verifica automatica delle regole in KiCad
Distanza di dispersione | il percorso lungo la superficie che la corrente può «strisciare»
OTA | «Over the Air» — aggiornamento del firmware via etere
NTP | servizio orario Internet che imposta l'orologio

## 17.4 Licenza e ringraziamenti

Questo manuale è distribuito con licenza CC BY-NC-SA 4.0. La struttura segue il regolamento documentale del progetto gemello AskSin-Analyzer: un indice con collegamenti diretti, regole di impaginazione fisse e il piè di pagina con il rimando al ritorno all'indice su ogni pagina.

L'autocostruzione avviene sotto la propria responsabilità. 230 volt sono pericolosi per la vita — in caso di dubbio rivolgersi a un elettricista qualificato.

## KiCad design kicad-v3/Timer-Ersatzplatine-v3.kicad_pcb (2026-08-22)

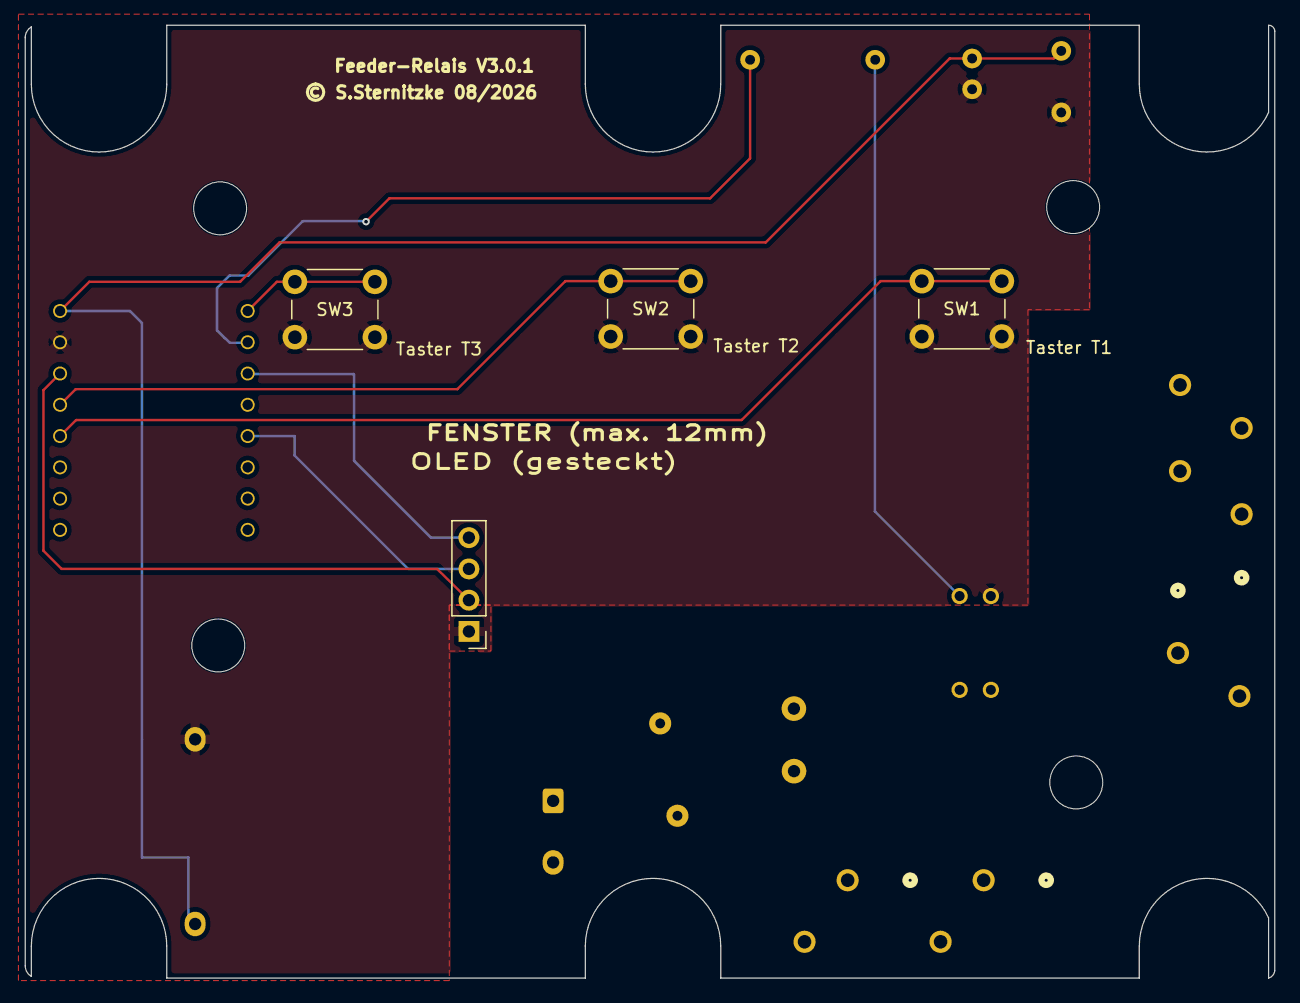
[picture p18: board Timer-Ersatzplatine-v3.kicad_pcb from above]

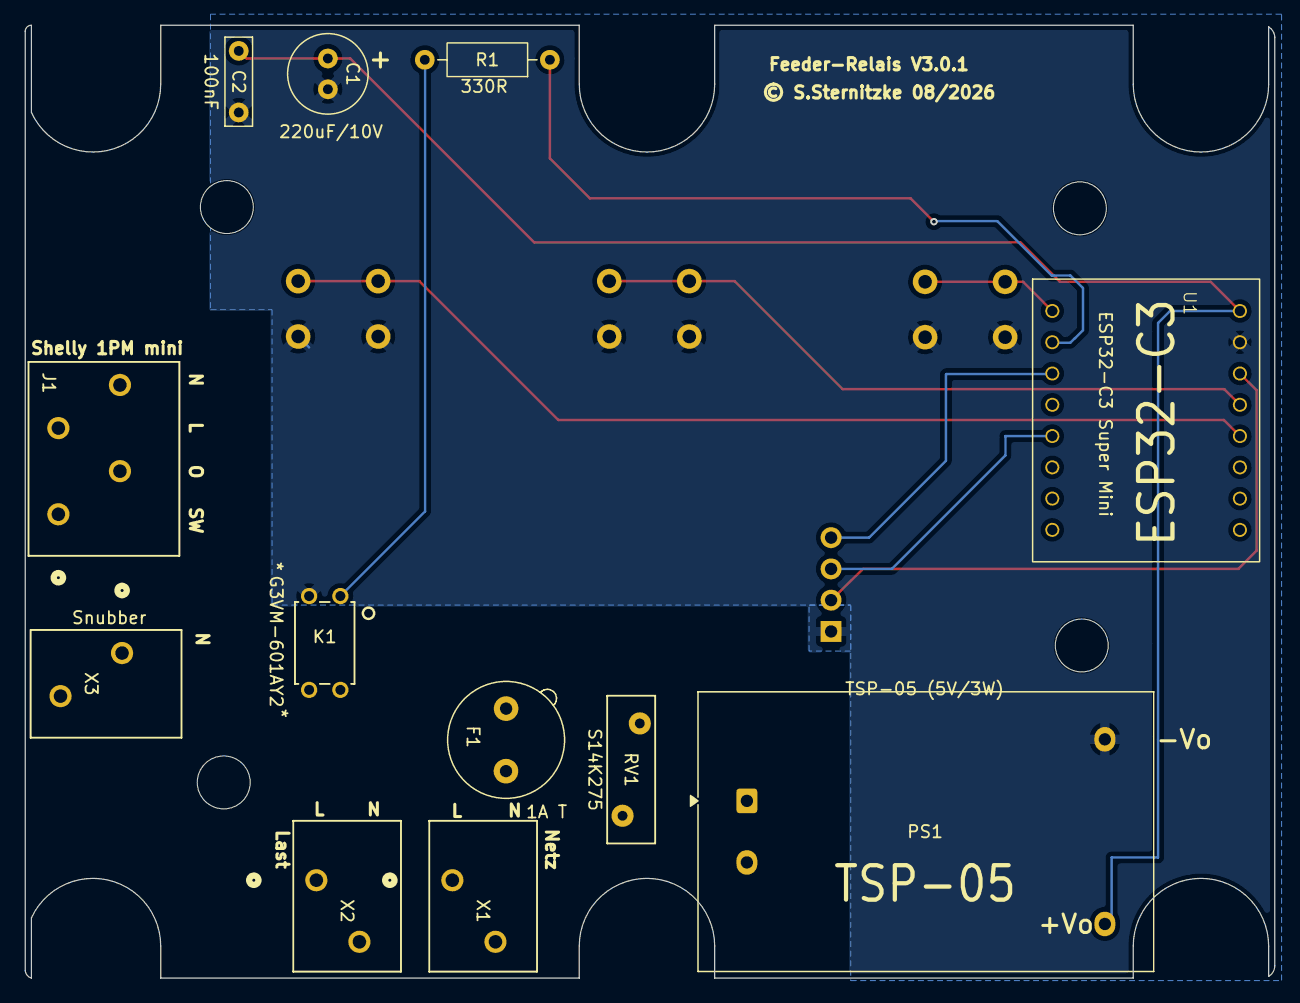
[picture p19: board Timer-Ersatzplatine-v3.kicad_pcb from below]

Board: 4 copper layers, 101.5 x 77.4 mm, 20 parts (12 on the bottom side), 15 nets.

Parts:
C1: 220uF/10V; C_Radial_D6.3mm_H11.0mm_P2.50mm
C2: 100nF; C_Rect_L7.0mm_W2.0mm_P5.00mm
F1: 1A T; Fuseholder_TR5_Littelfuse_No560_No460
J1: 250-204; CONN4_250-204_WAG
J4: OLED SSD1306 0,91 Zoll; PinHeader_1x04_P2.54mm_Vertical
K1: G3VM-601AY2; A-DIP4_THD_OMR
PS1: TSP-05 (5V/3W); Converter_ACDC_Hi-Link_HLK-PMxx
R1: 330R; R_Axial_DIN0207_L6.3mm_D2.5mm_P10.16mm_Horizontal
REF1, REF2, REF3, REF4: MountingHole_4.3mm_M4
RV1: S14K275; RV_Disc_D12mm_W3.9mm_P7.5mm
SW1: Taster T1; SW_PUSH_6mm
SW2: Taster T2; SW_PUSH_6mm
SW3: Taster T3; SW_PUSH_6mm
U1: ESP32-C3 Super Mini; ESP32-C3-SuperMini
X1: Netz; CONN2_250-202_WAG
X2: Last; CONN2_250-202_WAG
X3: Snubber; CONN2_250-202_WAG

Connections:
/+3V3: J4.2, U1.3V3
/+5V: C1.1, C2.1, PS1.4 (GND), U1.5V
/BTN1: SW1.1, U1.3 (GPIO3)
/BTN2: SW2.1, U1.4 (GPIO4)
/BTN3: SW3.1, U1.5 (GPIO5)
/L_F: F1.2, J1.3, K1.3, PS1.1 (AC-L), RV1.2
/L_IN: F1.1, X1.1
/N: J1.4, PS1.2 (AC-N), RV1.1, X1.2, X2.2, X3.1
/O_LAST: J1.2, X2.1, X3.2
/PMOS_DRV: R1.1, U1.6 (GPIO6)
/SCL: J4.3, U1.9 (GPIO9/SCL)
/SDA: J4.4, U1.7 (GPIO7/SDA)
/SW_SHELLY: J1.1, K1.4
GND: C1.2, C2.2, J4.1, K1.2, PS1.3 (+5V), SW1.2, SW2.2, SW3.2, U1.G
unnamed: K1.1, R1.2

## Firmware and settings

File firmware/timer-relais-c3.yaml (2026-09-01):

# =====================================================================
# Timer-Ersatzplatine: ESP32-C3 Super Mini + OLED 0,91" + PhotoMOS
# Pinbelegung passend zum KiCad-Schaltplan timer_ersatzplatine.kicad_sch
#   Taster S1/S2/S3 = Down/Manual / SET / UP: GPIO3 / GPIO4 / GPIO5
#     (gegen GND, interne Pullups)
#   PhotoMOS (-> Shelly SW): GPIO6 (ueber 330R an LED-Anode)
#   I2C OLED: SDA=GPIO7, SCL=GPIO9  (SDA war GPIO8 - kollidiert mit der RGB-LED!)
#   RGB-Status-LED (WS2812, onboard Super Mini): GPIO8
# =====================================================================

esphome:
  name: feeder-relais
  friendly_name: Feeder-Relais
  includes:
    - net_config.h
    - log_ring.h
    - help_content.h
    - timer_web.h
  on_boot:
    # Netzwerk-Konfig laden + anwenden, dann Web-App-Handler registrieren.
    priority: -100
    then:
      - lambda: |-
          esphome::netcfg_load();
          esphome::netcfg_apply_ntp();
          esphome::netcfg_apply_hostname();
          esphome::netcfg_apply_roaming();
          auto *h = new esphome::TimerWebHandler();
          h->time1 = id(time1);
          h->time2 = id(time2);
          h->time3 = id(time3);
          h->relay = id(shelly_trigger);
          h->remaining = &id(remaining);
          h->last_src = &id(last_src);
          h->rssi = id(wifi_rssi);
          h->uptime = id(uptime_s);
          h->ip = id(ip_addr);
          h->ssid = id(wifi_ssid_txt);
          h->mac = id(wifi_mac_txt);
          h->oled = id(oled);
          id(web_base)->add_handler(h);
          // WICHTIG: ohne natives web_server-UI startet den HTTP-Listener
          // (Port 80) sonst niemand im STA-Betrieb -> hier selbst initialisieren.
          id(web_base)->init();

esp32:
  board: esp32-c3-devkitm-1
  framework:
    type: arduino

logger:
  level: DEBUG            # bis DEBUG erfassen; Anzeige-Stufe waehlt man im Service-Tab
  on_message:
    # jede Log-Zeile in den Ringpuffer (aktiviert zugleich die Log-Listener)
    - lambda: 'esphome::log_ring_push(level, tag, message);'

api:

ota:
  - platform: esphome
  - platform: web_server   # Firmware-Upload per Browser: POST /update (Port 80)

wifi:
  # KEINE einkompilierten Zugangsdaten! Einrichtung ausschliesslich ueber das
  # Setup-AP/Captive-Portal. Vorteile:
  #  1) Auslieferung ohne fremden WLAN-Namen/-Passwort im Image.
  #  2) has_sta()==false -> die per Portal gespeicherten Daten liegen unter
  #     einem FESTEN Preference-Key (88491487) und ueberleben OTA-Updates
  #     (mit einkompiliertem WLAN haengt der Key am Config-Hash -> geht verloren).
  # Werksreset (keine alten Daten): Factory-Image MIT Flash-Erase flashen.
  power_save_mode: none
  # Maximale Sendeleistung (2,4-GHz-EU-/HW-Grenze = 20 dBm/100 mW). Stellt sicher,
  # dass der C3 nicht gedrosselt sendet. Der eigentliche Empfangsgewinn kommt aber
  # aus Antenne/Platzierung (Keramikantenne freistellen, weg vom Netzteil/Metall).
  output_power: 20dB
  # 802.11k/v (RRM/BTM) fest EINKOMPILIEREN (CONFIG_WPA_11KV_SUPPORT). Das ist
  # nur die Faehigkeit - das tatsaechliche Ein/Aus schaltet net_config.h zur
  # Laufzeit (set_btm/set_rrm), gesteuert per Web (Netzwerk-Tab, g_netcfg.roaming).
  enable_btm: true
  enable_rrm: true
  ap:
    ssid: "Feeder-Relais Setup"
    password: "feeder1234"
  on_connect:
    # Nach jedem Verbinden: statische IP + Hostname (DHCP-Name) erneut setzen
    # (per ESP-IDF-netif; DHCP ist Default, statisch wird nach Neustart aktiv).
    - lambda: |-
        esphome::netcfg_apply_static();
        esphome::netcfg_apply_hostname();

captive_portal:

# mDNS explizit (feeder-relais.local); noetig fuer die Laufzeit-Umbenennung
# via mdns_hostname_set() in net_config.h.
mdns:

# Kein natives web_server-UI mehr: die eigene Mobil-App/JSON-API laeuft auf
# web_server_base (Port 80, Default). captive_portal + OTA nutzen die Basis mit.
web_server_base:
  id: web_base

# Uhrzeit per NTP (Default de.pool.ntp.org; NTP-Server spaeter per Web - Stufe B)
time:
  - platform: sntp
    id: sntp_time
    timezone: "Europe/Berlin"
    servers:
      - de.pool.ntp.org

number:
  - platform: template
    name: "Zeit Taster 1"
    id: time1
    icon: mdi:timer-outline
    unit_of_measurement: "s"
    min_value: 1
    max_value: 600
    step: 1
    initial_value: 5
    restore_value: true
    optimistic: true
    mode: box
  - platform: template
    name: "Zeit Taster 2"
    id: time2
    icon: mdi:timer-outline
    unit_of_measurement: "s"
    min_value: 1
    max_value: 600
    step: 1
    initial_value: 10
    restore_value: true
    optimistic: true
    mode: box
  - platform: template
    name: "Zeit Taster 3"
    id: time3
    icon: mdi:timer-outline
    unit_of_measurement: "s"
    min_value: 1
    max_value: 600
    step: 1
    initial_value: 15
    restore_value: true
    optimistic: true
    mode: box
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

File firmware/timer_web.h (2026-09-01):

// ===========================================================================
// timer_web.h  –  Mobile Web-App + JSON-API für die Timer-Ersatzplatine
// ---------------------------------------------------------------------------
// Wird von timer-relais-c3.yaml über `esphome: includes:` eingebunden und in
// on_boot als AsyncWebHandler an web_server_base (Port 80) gehängt.
//
// Seiten (Single-Page, Tabs):  Bedienung · Einstellungen · Netzwerk · Status
// JSON-API (auch für ioBroker): GET /api/status, POST /api/trigger?button=N,
//                               POST /api/stop, POST /api/config?time1..3=
//
// Quelle der Wahrheit bleiben die ESPHome-Entitäten (time1/2/3, start_timer,
// shelly_trigger, remaining) – hier werden nur Zeiger darauf gehalten.
// ===========================================================================
#pragma once
#include "esphome.h"
#include <new>
#include <span>
#include <esp_system.h>
#include <esp_wifi.h>
#include "net_config.h"
#include "log_ring.h"
#include "help_content.h"   // HELP_DE/HELP_EN/HELP_FR (eingebettetes Handbuch)
#include "esphome/components/wifi/wifi_component.h"

// Geflashte Firmware-Version (im Status oben angezeigt). Bei jedem Release
// mitziehen (siehe Release-Ablauf / github-repo-Memory).
#define FW_VERSION "3.1.1"

namespace esphome {

// Projekt-Logo (Schaltpuls): wird als /favicon.svg ausgeliefert und im Tab gezeigt.
static const char LOGO_SVG[] PROGMEM = R"SVG(<svg xmlns="http://www.w3.org/2000/svg" viewBox="0 0 512 512"><defs><linearGradient id="b" x1="0" y1="0" x2="1" y2="1"><stop offset="0" stop-color="#0e7490"/><stop offset="1" stop-color="#0b3a4a"/></linearGradient></defs><rect x="20" y="20" width="472" height="472" rx="116" fill="url(#b)"/><circle cx="256" cy="256" r="150" fill="none" stroke="#67e8f9" stroke-width="40"/><path d="M300 150 L206 286 L252 286 L214 362 L318 224 L270 224 Z" fill="#fff"/></svg>)SVG";

static const char TIMER_INDEX_HTML[] PROGMEM = R"HTMLPAGE(<!doctype html>
<html lang=de><head><meta charset=utf-8>
<meta name=viewport content="width=device-width,initial-scale=1,viewport-fit=cover">
<title>Feeder-Relais</title>
<link rel=icon type="image/svg+xml" href="/favicon.svg">
<style>
:root{--bg:#0f1420;--card:#1a2232;--line:#232d42;--mut:#8595ad;--fg:#eef2f8;
--acc:#3b82f6;--ok:#22c55e;--warn:#f59e0b}
*{box-sizing:border-box}
body{margin:0;font:15px/1.45 system-ui,-apple-system,sans-serif;background:var(--bg);color:var(--fg)}
.wrap{max-width:480px;margin:0 auto;padding:14px 14px 88px}
h1{font-size:18px;margin:8px 2px 12px;display:flex;align-items:center;gap:9px}
.dot{width:11px;height:11px;border-radius:50%;background:var(--warn);flex:0 0 auto}
.dot.on{background:var(--ok);box-shadow:0 0 10px var(--ok)}
.card{background:var(--card);border-radius:14px;padding:16px;margin:10px 0}
.state{text-align:center;padding:24px 12px}
.state .big{font-size:44px;font-weight:700;letter-spacing:.5px;line-height:1}
.state .sub{color:var(--mut);margin-top:8px;font-size:14px}
.btns{display:grid;grid-template-columns:1fr 1fr 1fr;gap:10px}
button{font:inherit;color:var(--fg);background:var(--acc);border:0;border-radius:12px;
padding:15px 8px;cursor:pointer;-webkit-tap-highlight-color:transparent}
button:active{filter:brightness(.9)}
button.stop{background:#ef4444;width:100%;margin-top:10px;padding:14px}
.tb{display:grid;place-items:center;gap:3px}.tb b{font-size:15px}.tb span{font-size:12px;color:#cfe0ff}
label{display:block;color:var(--mut);font-size:13px;margin:12px 0 5px}
input,select{width:100%;font:inherit;color:var(--fg);background:#0d1424;border:1px solid #2b3855;
border-radius:10px;padding:12px}
.row{display:flex;justify-content:space-between;gap:10px;padding:10px 2px;border-bottom:1px solid var(--line)}
.row:last-child{border:0}.row .k{color:var(--mut)}.row .v{text-align:right;word-break:break-all}
nav{position:fixed;left:0;right:0;bottom:0;background:#131a29;border-top:1px solid var(--line);
display:flex;padding-bottom:env(safe-area-inset-bottom)}
nav a{flex:1;text-align:center;padding:11px 4px;color:var(--mut);font-size:12px;text-decoration:none}
nav a.act{color:var(--fg);box-shadow:inset 0 2px 0 var(--acc)}
.hide{display:none}
.note{color:var(--mut);font-size:12px;display:block;margin-top:10px;line-height:1.4}
.toast{position:fixed;left:50%;bottom:78px;transform:translateX(-50%);background:#26304a;
padding:10px 18px;border-radius:22px;opacity:0;pointer-events:none;transition:.3s}
.toast.show{opacity:1}
.foot{text-align:center;margin:20px 2px 6px}
.foot a{color:var(--mut);font-size:13px;text-decoration:none}
.foot a:active{color:var(--fg)}
</style></head><body>
<div class=wrap>
 <h1><span class=dot id=dot></span><span id=hdr>Feeder-Relais</span></h1>

 <section id=p_start>
  <div class="card state"><div class=big id=stBig>&ndash;</div><div class=sub id=stSub></div></div>
  <div class=btns>
   <button onclick="trig(1)"><span class=tb><b><span data-i18n=btn>Taster</span> 1</b><span id=t1s>&ndash;</span></span></button>
   <button onclick="trig(2)"><span class=tb><b><span data-i18n=btn>Taster</span> 2</b><span id=t2s>&ndash;</span></span></button>
   <button onclick="trig(3)"><span class=tb><b><span data-i18n=btn>Taster</span> 3</b><span id=t3s>&ndash;</span></span></button>
  </div>
  <button class=stop onclick="stop()" data-i18n=stop>Stopp</button>
 </section>

 <section id=p_cfg class=hide>
  <div class=card>
   <label data-i18n=cfg_t1>Zeit Taster 1 (Sekunden)</label><input id=c1 type=number min=1 max=600 inputmode=numeric>
   <label data-i18n=cfg_t2>Zeit Taster 2 (Sekunden)</label><input id=c2 type=number min=1 max=600 inputmode=numeric>
   <label data-i18n=cfg_t3>Zeit Taster 3 (Sekunden)</label><input id=c3 type=number min=1 max=600 inputmode=numeric>
   <button style="width:100%;margin-top:16px" onclick="save()" data-i18n=save>Speichern</button>
  </div>
 </section>
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

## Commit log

2026-07-13 Initiale Projektablage: Timer-Ersatzplatine (ESP32-C3 + OLED + Shelly 1PM Mini Gen4)
    Vollständiger Stand Phase 3 (Verifikation):
    - hardware/: parametrischer Geometrie-Generator (v8), generierte DXF,
    Vorschau-Render, KiCad-8-Schaltplan
    - firmware/: ESPHome-Konfiguration (timer-relais-c3.yaml)
    - docs/: Gesamtdoku und Projektplan als Markdown + generierte PDFs
    - tools/: md2pdf-Generator
    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
    [platine_original_geometrie.dxf, timer_ersatzplatine.kicad_sch]
2026-07-13 Geometrie v9: Schraubdome direkt vermessen + randoffene U-Schlitze
    Die 6 Gehäuse-Schraubdome sind statt geschlossener ⌀10-Bohrungen jetzt
    randoffene U-Schlitze (Breite 10) – toleranter beim Einsetzen, verzeiht
    Dom-Streuung entlang der Schlitzachse (Wunsch Silvio).
    Positionen direkt per Messschieber (Silvio 2026-07-13) statt aus dem
    Gehäusescan (dessen y-Registrierung bis 2,6 mm daneben lag):
    - Rasterabstand 45 mm, Reihenabstand 70 mm
    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
    [platine_original_geometrie.dxf]
2026-07-13 Firmware: mobile Web-App + JSON-API (Port 80) für Bedienung/Konfig/Status
    Neue, für Mobilgeräte optimierte Web-Oberfläche, die der ESP32 selbst auf
    Port 80 bereitstellt – als eigener AsyncWebHandler (firmware/timer_web.h)
    auf web_server_base; das native ESPHome-Web-UI ist deaktiviert.
    Vier Reiter:
    - Bedienung: 3 Taster auslösen + Live-Countdown + Stopp
    - Einstellungen: die 3 Timerzeiten (1..600 s, persistent)
    - Netzwerk: Hostname/IP/SSID/Signal/MAC/Setup-AP (Anzeige)
    - Status: Firmware, Laufzeit, freier Speicher, WLAN, Reset-Grund, Relais
    JSON-API (Query-Params, GET oder POST) – bedient Handy UND ioBroker:
    GET /api/status
    POST /api/trigger?button=N (bzw. ?seconds=N)
    POST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
    [timer-relais-c3.yaml, timer_web.h]
2026-07-13 Firmware Stufe A: Feeder-Relais - NTP-Uhr, Tasten-Automat, OLED-Redesign
    Gerät heißt jetzt "feeder-relais" (mDNS feeder-relais.local), AP
    "Feeder-Relais Setup". Vorbereitung für frei konfigurierbares WLAN:
    Erstzugang via AP/Captive-Portal (nativ), DHCP als Default.
    NTP-Uhr:
    - time: sntp, Default de.pool.ntp.org, Zeitzone Europe/Berlin
    Tasten-Zustandsautomat (S1 Down/Manual, S2 SET, S3 UP = GPIO3/4/5):
    - kurz S1/S2/S3 -> Timer 1/2/3 mit eingestellter Zeit
    - lang UP (S3) >=1,2 s -> alle Timer stopp + Shelly aus
    - lang SET (S2) >=3 s -> Info-Menü; darin S1 vor / S3 zurück,
    kurz SET oder 10 s ohne Druck -> zurück zum Normalzustand
    - Kurz-/Langdruck über on_press/on_release + millis();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
    [timer-relais-c3.yaml, timer_web.h]
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2026-07-13 Service-Tab: Live-Log/Debug (Ringpuffer) + Web-OTA + Neustart
    Neuer 5. Web-Reiter "Service" mit drei Bereichen:
    - Log/Debug: Live-Anzeige der letzten Log-Zeilen (Ringpuffer 40 Zeilen,
    firmware/log_ring.h), Anzeige-Stufe ERROR/WARN/INFO/DEBUG wählbar und
    ein-/ausschaltbar. Gespeist über `logger: on_message:` (aktiviert zugleich
    die ESPHome-Log-Listener), gelesen über GET /api/log?level=&since=.
    ANSI-Farbcodes/Steuerzeichen werden gefiltert. Logger jetzt auf level: DEBUG.
    - Firmware-Update (OTA): .bin-Upload per Browser über POST /update
    (ota: platform: web_server, läuft über web_server_base) — plus weiterhin
    Netzwerk-OTA via `esphome run` (platform: esphome, Port 3232).
    -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
    [timer-relais-c3.yaml, timer_web.h]
2026-07-13 Hostname zur Laufzeit konfigurierbar (mDNS + DHCP)
    ESPHomes mDNS nutzt auf ESP32 die ESP-IDF-mdns.h -> mdns_hostname_set()
    stellt den .local-Namen sofort um; esp_netif_set_hostname() setzt den
    DHCP-Namen (Router), der nach Reconnect/Neustart greift.
    - net_config.h: NetCfg v2 mit host[32] (Default feeder-relais),
    netcfg_sanitize_host() (gueltiges DNS-Label a-z/0-9/'-'),
    netcfg_apply_hostname() (mdns + netif); Prefs-Key neu ('NetD')
    - Anwendung: on_boot + wifi.on_connect; mdns: in der YAML explizit
    - Web: Hostname-Feld im Netzwerk-Reiter editierbar (+ /api/net?host=)
    - Korrigiert die fruehere Annahme "Hostname nur compile-zeitlich"
    Verifiziert mit `esphome compile` (ESP32-C3, Flash 54,3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
    [timer-relais-c3.yaml, timer_web.h]
2026-07-13 Doku: einsteigertaugliches Kapitel "Erstes Flashen" (Kap. 6.1-6.3) + Bilder
    - Neues Kapitel 6.1 Erstes Flashen Schritt-für-Schritt: Weg A (esphome run)
    und Weg B (Browser/esptool-js), mit Bild-Diagrammen (USB-Verbindung +
    Ablauf-Flowchart). 6.2 WLAN-Einrichtung über Captive-Portal, 6.3
    Problemlösung (Kabel/Boot-Modus/Treiber/dialout).
    - Klar dokumentiert, wo das fertige Image liegt:
    .esphome/build/feeder-relais/.pioenvs/feeder-relais/firmware.factory.bin
    (Voll-Image für Erstflash) bzw. firmware.bin (OTA).
    - docs/img/: flash_verbindung.png, flash_ablauf.png (mit PIL erzeugt).
    - tools/md2pdf.py: base_url gesetzt + img-CSS -> Bilder werden ins PDF
    eingebettet (im PDF geprüft).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
2026-07-15 Fix (Beta-1): HTTP-Server im STA-Betrieb starten + WLAN-Power-Save aus
    Gerätetest-Rückmeldung: Ping ok, aber keine Webseite auf Port 80 und
    schwankende Latenz ("mangelhaft").
    - Kein Webserver im Normalbetrieb: web_server_base wird sonst nur vom
    Captive-Portal (AP-Fallback) init()-siert; ohne natives web_server-UI
    ruft im STA-Betrieb niemand init() -> Listener startet nie. Fix: in
    on_boot id(web_base)->init() aufrufen (Handler ist bereits registriert).
    Damit funktioniert auch Web-OTA (POST /update) im Normalbetrieb.
    - Schwankende Latenz/"mangelhaft": wifi: power_save_mode: none.
    - firmware/build/ Images aktualisiert.
    Hinweis (Hardware, kein Firmware-Bug): OLED per I2C nicht erkann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
    [timer-relais-c3.yaml]
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2026-07-16 Hostname wirksam machen: Router (DHCP), Kopfzeile, Status + Kopf-Statuspunkt
    - Hostname erreicht jetzt den Router: netcfg_apply_hostname() startet bei
    Aenderung den DHCP-Client neu (esp_netif_dhcpc_stop/start) -> frisches
    DISCOVER mit Option 12; mDNS ohnehin sofort. Nur wenn abweichend vom
    Compile-Default.
    - Web-App zeigt den konfigurierten Hostnamen in der Kopfzeile und als
    Browser-Tab-Titel; /api/status.host = konfigurierter Name (g_netcfg.host).
    - Status-Reiter: neue Zeile "Hostname" zwischen Signal und IP-Adresse.
    - Statuspunkt in der Kopfzeile: gruen = ok, gelb = Timer laeuft,
    rot = Stoerung im Ruhezustand (OLED failed oder kein WLAN); /api/status
    liefert dazu "fault".
    - fi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
    [timer-relais-c3.yaml, timer_web.h]
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2026-07-16 RGB-LED zähmen: I2C-SDA -> GPIO7, WS2812 (GPIO8) als gedimmte Status-LED
    Die helle/warme Onboard-RGB-LED (WS2812) sitzt auf GPIO8 = bisher I2C-SDA;
    der I2C-Verkehr trieb sie hell an. Lösung:
    - I2C-SDA von GPIO8 auf GPIO7 verlegt (SCL bleibt GPIO9).
    - WS2812 auf GPIO8 als `light: esp32_rmt_led_strip`, im 1s-Interval gesetzt:
    grün=OK, gelb=Timer laeuft, rot=Stoerung, ~8% Helligkeit (kaum Waerme).
    - Konsistenz-Dreieck nachgezogen: Schaltplan-Pin GPIO8/SDA->GPIO7/SDA (Symbol
    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
    [timer_ersatzplatine.kicad_sch]
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2026-07-16 WLAN-Roaming 802.11k/v per Web schaltbar (Netzwerk-Tab)
    Fähigkeit fest einkompiliert (wifi: enable_btm/enable_rrm -> CONFIG_WPA_11KV_SUPPORT);
    Ein/Aus zur Laufzeit über g_netcfg.roaming (NetCfg v2->v3, persistent):
    netcfg_apply_roaming() setzt set_btm/set_rrm + gegengleich set_post_connect_roaming.
    Web-Checkbox + POST /api/net?roaming=0|1. Bits greifen ab nächstem (Re)Connect.
    Doku/Projektplan/PDFs + build-Images (Leak-Check sauber) nachgezogen.
    [timer-relais-c3.yaml, timer_web.h]
2026-07-16 Netzwerk-Tab: Knopf "Jetzt neu verbinden" (WLAN-Reconnect ohne Reboot)
    POST /api/reconnect setzt g_reconnect_pending; das 1s-Interval ruft dann
    netcfg_wifi_reconnect() = wifi.disable()+enable(). start() baut die STA-Config
    neu auf -> geaenderte Roaming-Bits (btm/rrm) werden sofort aktiv, ohne Neustart.
    Verzoegerung ueber das Interval, damit die HTTP-Antwort noch rausgeht (WLAN
    reisst danach kurz ab). Doku/Projektplan/PDFs + build-Images nachgezogen.
    [timer-relais-c3.yaml, timer_web.h]
2026-07-16 Mehrsprachigkeit DE/EN/FR: Web-App + OLED + Handbuch (EN/FR)
    Firmware:
    - Sprache geraeteweit in g_netcfg.lang (NetCfg v3->v4, netcfg_lang_idx()),
    Auswahl per Dropdown ganz oben im Zeiten-Tab, POST /api/net?lang=de|en|fr.
    - Web: JS-Woerterbuch T{key:{de,en,fr}} + data-i18n-Attribute, tr()/applyStatic();
    WLAN-/Reset-Status als neutrale Codes aus C++ (up/down, poweron/...),
    Uebersetzung im Browser. Umschalten ohne Neuladen.
    - OLED: Sprach-Tabellen fuer Wochentage/Status(Ruhe/Futter)/Menue, akzentfrei.
    - Logs + Captive-Portal bleiben englisch (ESPHome-Kern).
    Doku:
    - DOKUMENTATION.md (DE, fuehrend) um Sprachfeature erweitert; Handbuch zusaetzlich
    in DOKUMENTATION.en.md + DOKUMENTATION.fr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
    [timer-relais-c3.yaml, timer_web.h]
2026-07-16 timer_web.h: url() -> url_to() (entfaellt in ESPHome 2026.9.0)
    Deprecation beseitigt: handleRequest()/canHandle() lesen die URL jetzt ueber
    req->url_to(buffer) (StringRef in eigenen Puffer, Bibliotheks-Idiom) statt des
    ab 2026.9.0 entfallenden req->url(). Rein intern, keine Funktionsaenderung.
    Compile gruen, keine Deprecation-Warnung mehr; build-Images (Leak-Check sauber).
    [timer_web.h]
2026-07-16 Roaming-Haken: persistent, laufend sichtbar + Status-Zeile EIN/AUS
    Fix des "verschwindenden" Hakens:
    - Ursache: ESPHome-save() legt auf ESP32 nur in die RAM-Warteschlange
    (s_pending_save); ins Flash kommt es erst beim periodischen sync().
    netcfg_save() ruft jetzt global_preferences->sync() -> sofort dauerhaft
    (gilt fuer alle Netzwerk-Einstellungen).
    - roaming ist jetzt Teil von /api/status; der Haken wird laufend daraus
    gesetzt (self-healing, 4-s-Hold nach manueller Aenderung) und bleibt nach
    dem Neuverbinden sichtbar gesetzt.
    - Neue Status-Zeile "WLAN-Roaming (802.11k/v): EIN/AUS".
    Doku DE/EN/FR + PDFs + Projektplan nachgezogen; build-Images (Leak-Check sauber).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
    [timer_web.h]
2026-07-16 Fix Panik-Neustarts (Preferences aus Webserver-Task) + Version im Status
    - Ursache der haeufigen Panik-Resets: netcfg_save() lief im Webserver-Task und
    rief seit v0.0.13 global_preferences->sync(); ESPHomes Preferences
    (s_pending_save-Vektor + NVS-Handle) sind aber NICHT threadsicher gegen den
    Main-Task -> Data-Race/Heap-Korruption -> ESP_RST_PANIC.
    Fix: netcfg_save() setzt nur g_prefs_save_pending; das 1s-Interval (Main-Task)
    ruft netcfg_flush() = save()+sync(). Alle Flash-Schreibzugriffe single-threaded.
    - Neu: geflashte Version (FW_VERSION) als "ver" in /api/status; erste Status-Zeile
    "Version". Bei jedem Release FW_VERSION in timer_web.h mitziehen.
    - Doku DE/EN/FR (Persistenz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
    [timer-relais-c3.yaml, timer_web.h]
2026-07-16 Fix Stack-Overflow im httpd-Task (echte Crash-Ursache) -> Heap-Puffer
    Serielles Log: "Guru Meditation Error ... Stack protection fault ... task httpd",
    ausgeloest sobald die offene Web-App /api/status pollt. Der httpd-Task hat nur
    ~4 KB Stack; send_status (buf[896]) + handleRequest (urlbuf[513]) + snprintf lagen
    gleichzeitig darauf -> Ueberlauf -> Panik-Reset-Loop (auch OTA kam nicht durch).
    Fix: alle grossen Handler-Puffer auf den HEAP (new(std::nothrow)/delete[]):
    - send_status-JSON (960)
    - send_net-JSON (520)
    - URL-Puffer in handleRequest (url_to via std::span)
    Der Preferences-Fix aus v0.0.14 bleibt (richtig, aber nicht die Absturzursache).
    FW_VERSION 0.0.15. esphome compile gruen; build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
    [timer_web.h]
2026-08-12 v2: Handbuch nach asksin-Regelwerk + kritischer SDA-Fix (GPIO8->GPIO7)
    Board<->Firmware-Audit ergab: OLED-SDA lag auf der v2-Platine faelschlich auf
    GPIO8 (= Onboard-WS2812) - beim Ableiten aus v1 war die 2026-07-16-Korrektur
    verlorengegangen. Ohne Fix: OLED tot + LED/I2C-Konflikt, Geraet unbrauchbar.
    Fix (nur Board, Firmware unveraendert):
    - Schaltplan-Pin GPIO8/SDA -> GPIO7/SDA (number 8->7, Symbol + Instanz)
    - Layout: /SDA von U1-Pad 8 auf Pad 7, Pad 8 netzlos, GND-Zonen neu gefuellt
    - Verifiziert: Netzliste /SDA->U1.7, /SCL->U1.9, U1.8 frei; DRC 0 clearance/
    0 creepage/0 unrouted (nur harmlose lib_footprint-Warnungen)
    Dokumentation (asksin-Regelwerk):
    - Neues Handbuch docs/handbuch/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
    [Timer-Ersatzplatine-v2-BOARD.stl, Timer-Ersatzplatine-v2.kicad_pcb, Timer-Ersatzplatine-v2.kicad_sch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]
2026-08-12 SDA geradlinig geroutet (senkrecht + eine Diagonale, wie SCL)
    Der SDA-Fix-Track lief zuvor diagonal von Pad 7 quer zum OLED. Jetzt im
    Hausstil: senkrecht die Pad-Spalte herunter (x=140.589) bis y=88.646,
    dann eine Diagonale zu J2.4 - parallel zu SCL. DRC unveraendert sauber
    (0 clearance/creepage/unrouted). Zonen neu gefuellt.
    [Timer-Ersatzplatine-v2.kicad_pcb]
2026-08-12 SW4/X4 aus Schaltplan entfernt + Display 180 Grad in Firmware
    - SW4 (altes On-Board-Shelly) und X4 (On-Board-Snubber) aus dem Schaltplan
    entfernt (waren nicht auf dem PCB); Schaltplan valide, 20 Komponenten.
    - Display: rotation: 180 Grad in der ESPHome-Config (Montage verdreht) -
    reine Firmware-Loesung, keine Platinenaenderung, einzeilig reversibel.
    - Doku-Note aktualisiert: J3-J6 bleiben als OLED-Header-Alternativen (noch
    aufs PCB zu platzieren), SW4/X4 entfernt.
    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
    [Timer-Ersatzplatine-v2.kicad_sch]
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2026-08-12 J3-J6 + Neurouting (Nutzer) integriert; alle DRC-Fehler behoben; K1-SELV in GND-Flaeche
    Nutzer (GUI): J3-J6 als OLED-Reserve-Header rechts neben J2 platziert+geroutet,
    F1 gedreht/versetzt, Beschriftungen korrigiert, Platine neu geroutet.
    Headless-Fixes danach:
    - 4 GND-Zonen neu angelegt (waren beim GUI-Routing verloren) + gefuellt
    - Short /SDA<->/+3V3: +3V3-In1-Bahn im orthogonalen Jog um U1.7 gefuehrt
    - Kupfer-Rand: +5V (In2) vom Dom-Schlitz weg; PMOS-Diagonale -> orthogonaler L
    - Text: 'N' (B.Silk) gespiegelt, J1-Value entspiegelt
    - L_F-Zufuehrung J1.3 suedlich um K1 (45-Grad-Ast, B.Cu-Unterfuehrung unter
    /SW_SHELLY mit 2 Vias, orthogonal in K1.4) -> real >=6mm von K1.2
    - GND-Flaechen-E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
    [Timer-Ersatzplatine-v2.kicad_pcb, Timer-Ersatzplatine-v2.kicad_sch]
2026-08-12 Dom-Schlitze Ø10 -> Ø11 (rechte zwei asymmetrisch), Attrappe + Doku nach
    - 4 Schlitze symmetrisch r5->5.5 (Waende +-0.5, Boden +0.5); linke Ecken-
    boegen an neue Waende angepasst (Schnittpunkte berechnet)
    - 2 rechte Schlitze asymmetrisch: innen/Boden +0.5, Aussenwand bleibt an
    x=204.546 - zur Board-Kante (205.05) sind nur 0.5mm Material, jede
    Verbreiterung nach aussen ergaebe einen unfertigbaren Haarsteg
    - +5V(In2)/PMOS(F.Cu)-Bahnen unterm oberen Mittelschlitz auf y=61.45
    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
    [Timer-Ersatzplatine-v2-BOARD.stl, Timer-Ersatzplatine-v2.kicad_pcb]
2026-08-12 Projektlokale Footprint-Libs + Wago-3D-Modelle implementiert
    - fp-lib-table auf ${KIPRJMOD} umgestellt (vorher tote KICAD10_*-Variablen)
    und ESP32-C3-SuperMini-Lib ergaenzt -> funktioniert in jedem Klon
    - Wago 250.pretty + Wago 250.3dshapes ins Repo (Nutzer-Dateien)
    - 3D-Modelle verdrahtet (Nutzer-Werte): 250-202 an X1/X2/X3 rot(90,0,270)
    off(1.75,0,0); 250-204 an J1 rot(90,0,270) off(12.3,-5,0) - Board + Lib
    - G3VM_601AY2 + ESP32-C3-SuperMini Footprints aus dem Board in .pretty-Libs
    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
    [Timer-Ersatzplatine-v2.kicad_pcb]
2026-08-12 Wago-3D-Transforms tatsaechlich in die Board-Datei geschrieben
    Vorheriger Commit hatte die Modelle faelschlich bei (0,0,0): pcbnew
    persistiert Aenderungen an fp.Models()-Elementen nicht (Kopien). Jetzt
    per direkter Datei-Bearbeitung gesetzt + per Readback verifiziert:
    250-202 (X1/X2/X3): rotate(90 0 270) offset(1.75 0 0)
    250-204 (J1): rotate(90 0 270) offset(12.3 -5 0)
    Show=True, DRC unveraendert (0 echte Fehler). Hinweis: kicad-cli render
    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
    [Timer-Ersatzplatine-v2.kicad_pcb]
2026-08-12 Wago-3D-Modelle um 180 Grad gedreht (Z 270 -> 90), Offsets unveraendert
    Nutzer: Position stimmt, nur 180-Grad-Drehung noetig. Alle 4 Wago
    (250-202 X1/X2/X3 + 250-204 J1) Z-Rotation +180 -> rotate(90 0 90),
    Board + Lib-Dateien, Readback verifiziert.
    [Timer-Ersatzplatine-v2.kicad_pcb]
2026-08-12 K1/U1 3D-Modelle (STEP) ins Repo + Pfade auf ${KIPRJMOD}
    - A-DIP4_THD_OMR.step (Omron PhotoMOS) + ESP32-C3 SuperMini STEP (Nutzer
    abgelegt) in kicad-v2/G3VM_601AY2.3dshapes bzw. ESP32-C3-SuperMini.3dshapes
    - Board + beide .pretty-Footprints: K1/U1-Modellpfade ${KICAD10_3DMODEL_DIR}
    -> ${KIPRJMOD} (direkte Datei-Bearbeitung; pcbnew persistiert das nicht)
    - Render bestaetigt: ESP32-C3-Modell laedt; DRC unveraendert
    - Repo jetzt self-contained (Wago + G3VM + ESP32 Footprints + 3D)
    [Timer-Ersatzplatine-v2.kicad_pcb]
2026-08-12 Wago-3D-Ausrichtung korrigiert: X 90 -> -90 (Ruecksseiten-Flip)
    Footprints bleiben korrekt hinten (B.Cu). KiCad spiegelt 3D-Modelle auf
    Rueckseiten-Footprints -> die aus dem (Vorderseiten-)Vorschaufenster
    gesetzten Werte kippten die Klemmen durch die Platine. Empirisch per
    Schraeg-Render verifiziert: rotate(-90 0 90) laesst alle vier (X1/X2/X3
    250-202, J1 250-204) flach auf der Rueckseite sitzen, Drahteinfuehrung
    zugaenglich. Offsets unveraendert. Board + Libs + Handbuch-Renders.
    [Timer-Ersatzplatine-v2.kicad_pcb]
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2026-08-13 Platinen-Attrappe (Testdruck) auf 1,6 mm Dicke korrigiert
    box/Timer-Ersatzplatine-v2-BOARD.stl war 2,54 mm dick (aus KiCads unangepasstem
    4-Lagen-Stackup mit 2,63 mm Summe). Auf die dokumentierte Standard-Enddicke
    1,6 mm gesetzt (Umriss, Loecher und Rand-Schlitze unveraendert), damit die
    Passprobe im gedruckten Rueckteil zur real bestellten 1,6-mm-Platine passt.
    [Timer-Ersatzplatine-v2-BOARD.stl]
2026-08-19 Fix: ESP-GND war nicht angebunden (Pad "GND" vs. Symbol-Pin-Nr. "G")
    Am ESP kam keine Masse an: Der ESP32-C3-Footprint hatte das Ground-Pad "GND"
    benannt, das Symbol jedoch die Pin-NUMMER "G". KiCad mappt Pin-Nummer -> Pad-Name,
    "G" != "GND" -> das GND-Pad blieb ohne Netz (die Masseflaechen gossen mit Abstand
    darum herum). Der ESP lief daher nur per USB (dort liefert das Kabel die Masse).
    Fix: Footprint-Pad an die Symbol-Pin-Nummer angeglichen ("GND" -> "G", in
    ESP32-C3-SuperMini.pretty UND im Board), Pad aufs GND-Netz gelegt, Zonen neu
    gefuellt. Pad sitzt in allen 4 Masseflaechen -> bondet direkt.
    Verifiziert: U1.G auf GND, DRC 0 unverbundene Elemente.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
    [Timer-Ersatzplatine-v2.kicad_pcb]
2026-08-19 v3.0.0: Board-Re-Layout (ESP links unter TSP-05) + Projekt v2->v3
    Elektronik-Neuplatzierung auf der Rueckseite:
    - ESP32-C3 um 90 Grad gedreht in die linke Spalte unter TSP-05 (USB-C nach oben)
    - J4 (OLED-Header) 3 mm naeher an TSP-05
    - J2/J3/J5/J6 aus Schaltplan UND Board entfernt (nur J1/J4 bleiben)
    - PS1-Polaritaet korrigiert (+5V/GND getauscht; TSP-05-Symbolfehler)
    - Kleinspannung (BTN/PMOS/I2C/5V/3V3) neu geroutet
    - DRC: 0 unverbunden, 0 Kriechstrecken-/Clearance-Verstoss (6-mm-Regel greift);
    Rest kosmetische lib_footprint- + vorbestehende PS1-Silk-Hinweise
    - Konsistenz-Viereck geprueft: U1-Pads = Firmware (SDA=GPIO7, SCL=GPIO9, GPIO8 frei)
    Projekt v2 -> v3 umbenannt (Nutzerwunsch "al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
    [Timer-Ersatzplatine-v2.kicad_pcb, Timer-Ersatzplatine-v2.kicad_sch, Timer-Ersatzplatine-v3.kicad_pcb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]
2026-08-20 v3.0.1: K1 3/4-Tausch, 230V auf Innenlagen, J4-Drehung (GND unten)
    Aufbauend auf v3.0.0 (Re-Layout + Umbenennung), Board-Feinschliff:
    - K1 (PhotoMOS) Pin 3/4 getauscht (Schaltplan + Board) -> L_F via-los geroutet
    - Alle 230V-Bahnen auf Innenlagen verschoben: F.Cu->In1, B.Cu->In2
    (Aussenflaechen 230V-frei/beruehrsicher; GND-Zonen identisch, DRC sauber)
    - J4 (OLED-Header) um 180 Grad gedreht: GND jetzt unten zu PS1;
    Reihenfolge GND/VCC/SCL/SDA, neu geroutet, GND-Zone um J4.1 ergaenzt
    - Schwachstrom-Bahnen + Silk (Nutzer-GUI) nachgezogen
    - DRC: 0 unverbunden, 0 Clearance/Kriechstrecke/Short (nur kosmetische Silk)
    - FW_VERSION 3.0.0 -> 3.0.1; firmware/build/ neu kompiliert
    Finale GUI-DRC-Kr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
    [Timer-Ersatzplatine-v3.kicad_pcb, Timer-Ersatzplatine-v3.kicad_sch]
2026-08-20 v3.0.2: Status-LED-Prioritaet + WebUI-Helligkeitsregler
    Firmware-Patch (Board unveraendert v3.0.1):
    - Status-LED (WS2812): Timer hat jetzt Vorrang vor Stoerung (wie WebUI-Punkt)
    -> beim Fuettern gelb, auch ohne OLED; rot nur im Ruhezustand bei Stoerung
    - WebUI: Helligkeitsregler fuer die Status-LED (0..100 %, persistent, Default 25 %)
    im Service-Tab (Karte "Geraet"); Sprachauswahl ebenfalls dorthin verschoben
    -> Zeiten-Tab enthaelt nur noch die drei Taster-Zeiten
    - net_config: NetCfg-Version 4->5 (neues Feld led_bri); behebt zugleich einen
    vorbestehenden Persistenz-Bug (defaults setzten v3, Load prueft v4 -> Netz-
    Config ging bei jedem Reboot verloren). WLAN-Daten bleiben; IP/NTP/H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
    [timer-relais-c3.yaml, timer_web.h]
2026-08-22 v3.0.3: PS1-Polaritaet korrigiert (+5V/GND) + Routen-Feinschliff
    Board-Korrektur (kritisch):
    - PS1 (TSP-05) DC-Ausgang richtiggestellt: PS1.3 = GND (-Vo, Mitte),
    PS1.4 = +5V (+Vo, Rand) -- deckungsgleich mit Modul-Pinout, Silkscreen
    UND Schaltplan. In v3.0.0 war die Polaritaet versehentlich gedreht worden.
    - +5V rechts an der Rand-Aussparung vorbei zu PS1.4 (+Vo) gefuehrt; +5V -> U1.5V.
    - Einige Schwachstrom-Routen nachkorrigiert (Nutzer, GUI).
    - DRC: 0 unverbunden, 0 Clearance/Kriechstrecke/Short/Randabstand.
    - Gerber (4-lagig) neu aus dem korrigierten Board.
    - FW_VERSION 3.0.2 -> 3.0.3 (Versions-Bump; Firmware funktional = 3.0.2).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
    [Timer-Ersatzplatine-v3.kicad_pcb]
2026-08-27 Firmware v3.1.0: expose the trigger source (button/api/adapter) in status, log and web UI
    /api/trigger now reads an optional &src (the ioBroker adapter sends
    &src=adapter); every start records where it came from:
    - new ESPHome global last_src (0 button / 1 api / 2 adapter, -1 none), also
    set by the three physical buttons, wired into the web handler in on_boot.
    - /api/status gains a "trg" field (button/api/adapter/none).
    - a log-ring line "Start via <source> (Ns)" on each start.
    - new "Trigger" row in the web UI status table (i18n, 6 languages).
    - FW_VERSION -> 3.1.0.
    Docs: help pages (6 languages, regenerated help_content.h) fix the trigger
    row (button/seconds instead of the outdated ch)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
    [timer-relais-c3.yaml, timer_web.h]
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

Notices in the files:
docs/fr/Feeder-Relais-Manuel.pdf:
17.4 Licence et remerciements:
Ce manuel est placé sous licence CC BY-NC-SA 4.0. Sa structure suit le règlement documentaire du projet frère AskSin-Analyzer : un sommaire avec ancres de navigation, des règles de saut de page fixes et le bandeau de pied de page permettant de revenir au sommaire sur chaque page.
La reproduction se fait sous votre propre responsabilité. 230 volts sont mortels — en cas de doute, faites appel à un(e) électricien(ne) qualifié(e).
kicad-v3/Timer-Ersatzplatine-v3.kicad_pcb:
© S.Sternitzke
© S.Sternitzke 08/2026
